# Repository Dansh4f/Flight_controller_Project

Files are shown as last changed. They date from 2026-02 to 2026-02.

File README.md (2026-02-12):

# STM32F405 Flight Controller — Custom PCB Design

A compact, manufacturing-ready flight controller PCB designed around the STM32F405RGT6 (ARM Cortex-M4). This repository contains the Altium source files for a two-layer board focused on clean power distribution, modular sensor integration, and reliable communication for embedded flight applications.

## Highlights

- Core MCU: STM32F405RGT6 (Cortex-M4 @ 168 MHz)
- Sensors: BNO055 (IMU), MS5611 (barometer), depth sensor
- Wireless/comms: UWB (SPI interface), GPS (UART), SBUS receiver input
- Interfaces: multiple SPI buses, shared I2C, UARTs, USB
- Motor PWM outputs with dedicated connector
- On-board 3.3V regulation and input protection (BAT54C + MIC5504 LDO)

## System Overview

The design integrates MCU, sensors, and power subsystems to provide a reliable flight controller platform. Main subsystems:

- MCU core and support circuits (oscillator, VCAP, decoupling, reset/boot)
- Power input protection and 3.3V regulation
- Sensor interfaces (I2C and SPI) and connectors for expandability
- SBUS receiver input conditioning and motor PWM outputs
- USB for programming and diagnostics

## Microcontroller & Board Considerations

Design decisions made for the `STM32F405RGT6`:

- Individual decoupling capacitors for each VDD/VDDA pin
- Required VCAP caps and analog filtering for stable operation
- Ferrite bead isolation for analog supply (3.3VA)
- External crystal oscillator with proper load capacitors
- Boot configuration and reset network implemented for robust programming

## Power Architecture

Input sources:

- USB 5V (programming/power)
- External 5V header (battery or regulated input)

Protection & regulation:

- BAT54C Schottky diode for input protection/OR-ing
- MIC5504 LDO to provide regulated 3.3V to MCU and sensors
- Short, wide power traces and a bottom-layer ground pour for low impedance
- Proper input/output decoupling and via stitching for returns

Power routing was prioritized in layout to minimize noise injection into analog circuits.

## Sensors & Peripherals

- BNO055 IMU — I2C, with reset/interrupt lines routed
- MS5611 barometer — SPI with dedicated CS and local decoupling
- UWB module — SPI2 bus with IRQ and reset
- Depth sensor — I2C on the shared sensor bus
- GPS — UART interface on dedicated header

Components are placed and routed to keep analog sensors away from high-current traces.

## Communications & Signal Conditioning

- Multiple SPI buses isolate high-speed peripherals for signal integrity
- Shared I2C bus enables sensor expansion
- UARTs for GPS and debug
- SBUS receiver input uses an NPN transistor-based level shifter and pull-ups for reliable logic levels

## Motor PWM

Motor outputs are brought to a dedicated connector with shield/ground considerations and short route lengths from the MCU PWM pins.

## PCB Layout Strategy

- 2-layer PCB with bottom ground plane
- Ground via stitching in key areas
- Routing priority: power → decoupling → high-speed SPI → connectors
- Controlled trace widths for power, short SPI routes, and clear mechanical anchor points

## Files in this repository

- `Flight_controller_Project.PrjPcb` — Altium project file
- `PCB1.PcbDoc` — PCB layout document
- `Sheet1.SchDoc`, `Sheet2.SchDoc`, `Sheet3.SchDoc` — schematic pages
- `*.SchLib`, `*.PcbLib` — component libraries
- `Project Outputs for Flight_controller_Project/` — generated outputs (DRC, HTML reports)
- `.gitignore` — rules to exclude generated and temp files

## How to open (Altium Designer)

1. Open Altium Designer.
2. `File → Open Project` and choose `Flight_controller_Project.PrjPcb`.
3. Open schematic and PCB documents as needed.

## PCB Preview — 3D View

The image below is a 3D rendered view of the Flight Controller PCB (top side). It highlights component placement, connector locations, and the overall board layout intended for manufacturing and mechanical integration.

<p align="center">
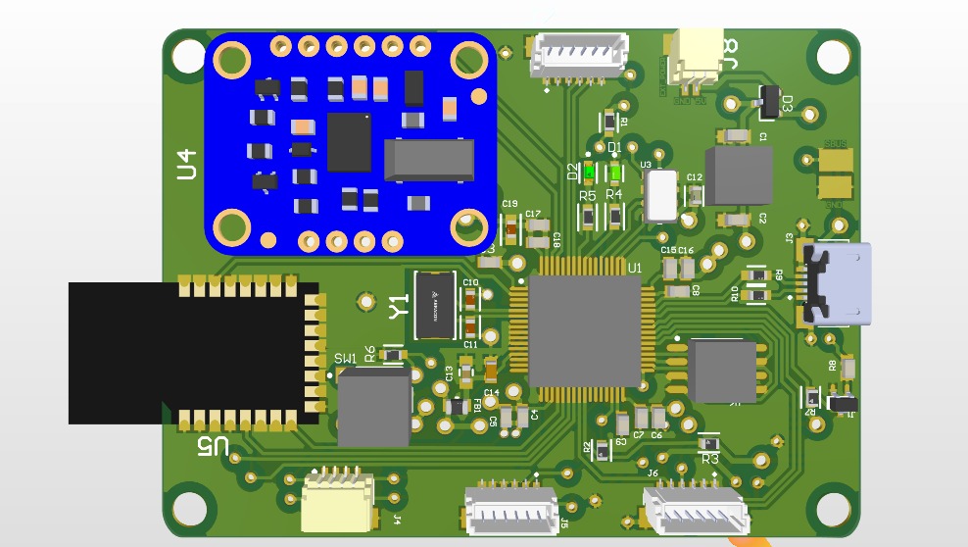
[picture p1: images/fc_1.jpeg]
3D render of Flight Controller PCB
	
</p>

## Contact

**Author:** Swastik Kumar

---

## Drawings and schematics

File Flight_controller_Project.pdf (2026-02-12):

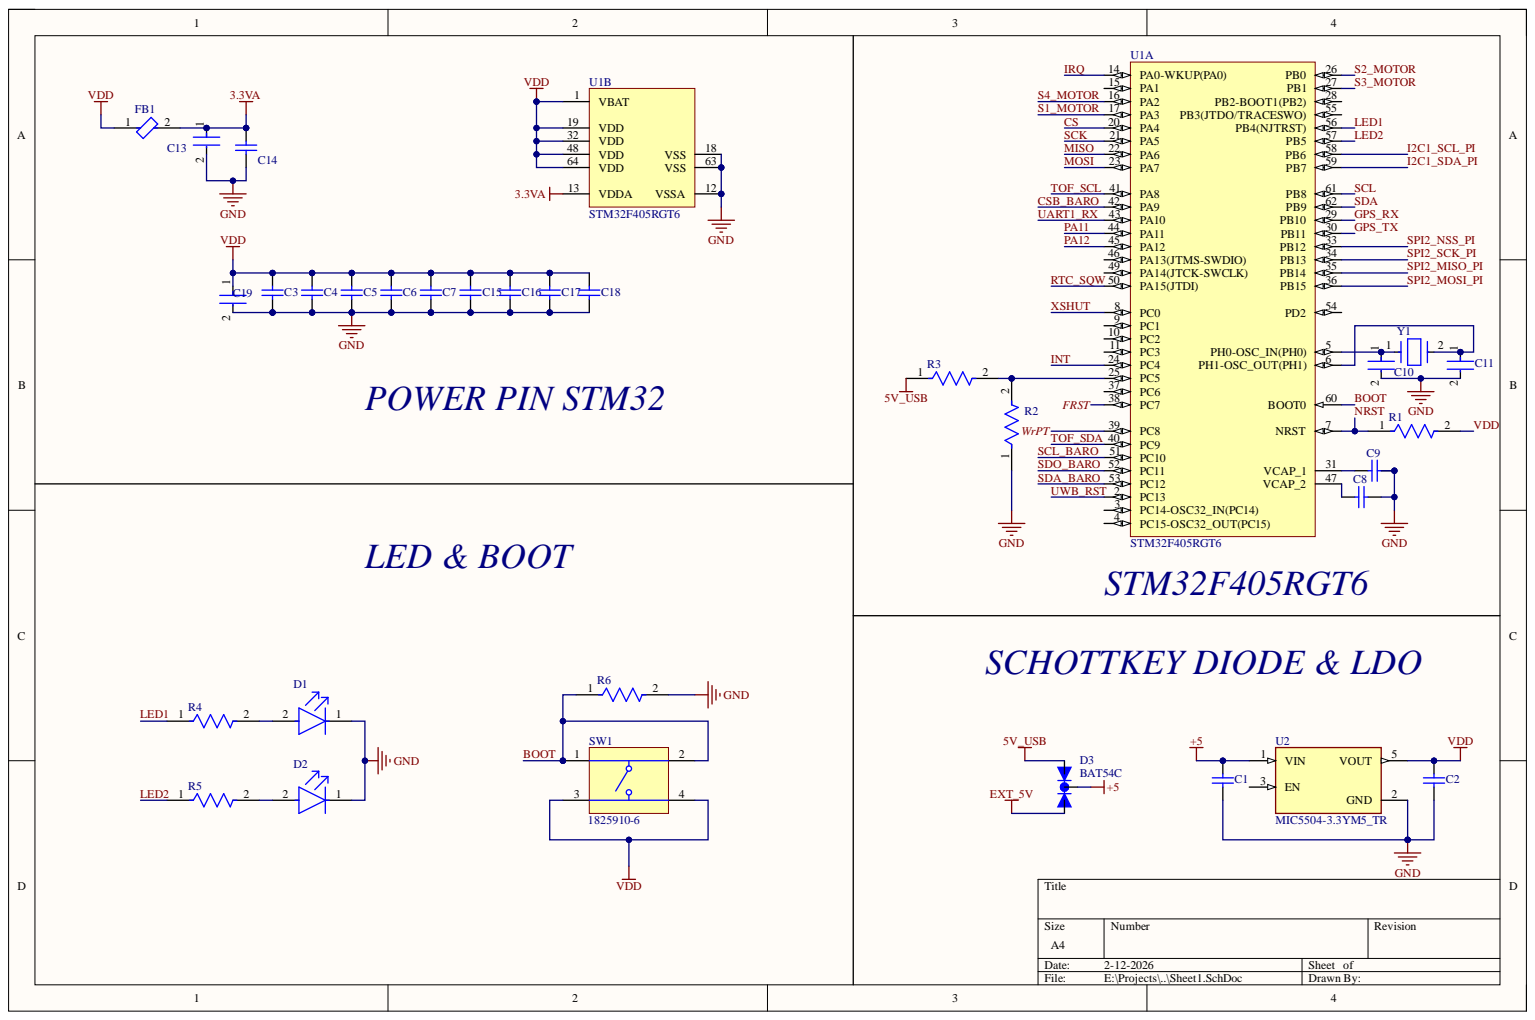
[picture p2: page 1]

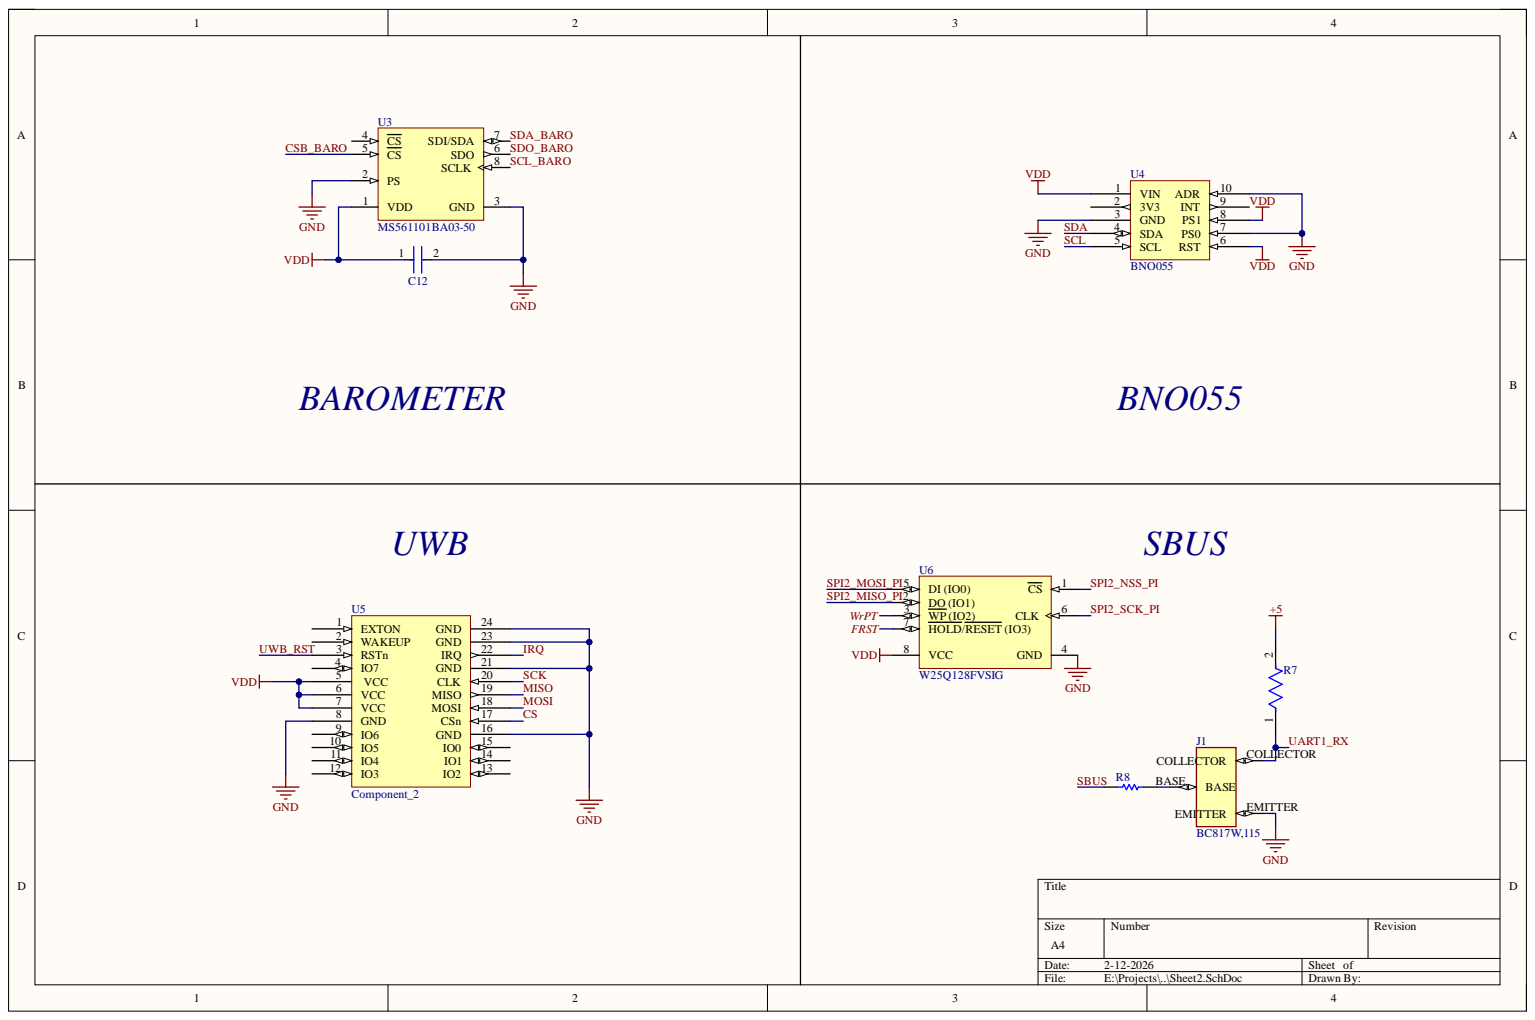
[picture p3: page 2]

VCC 7

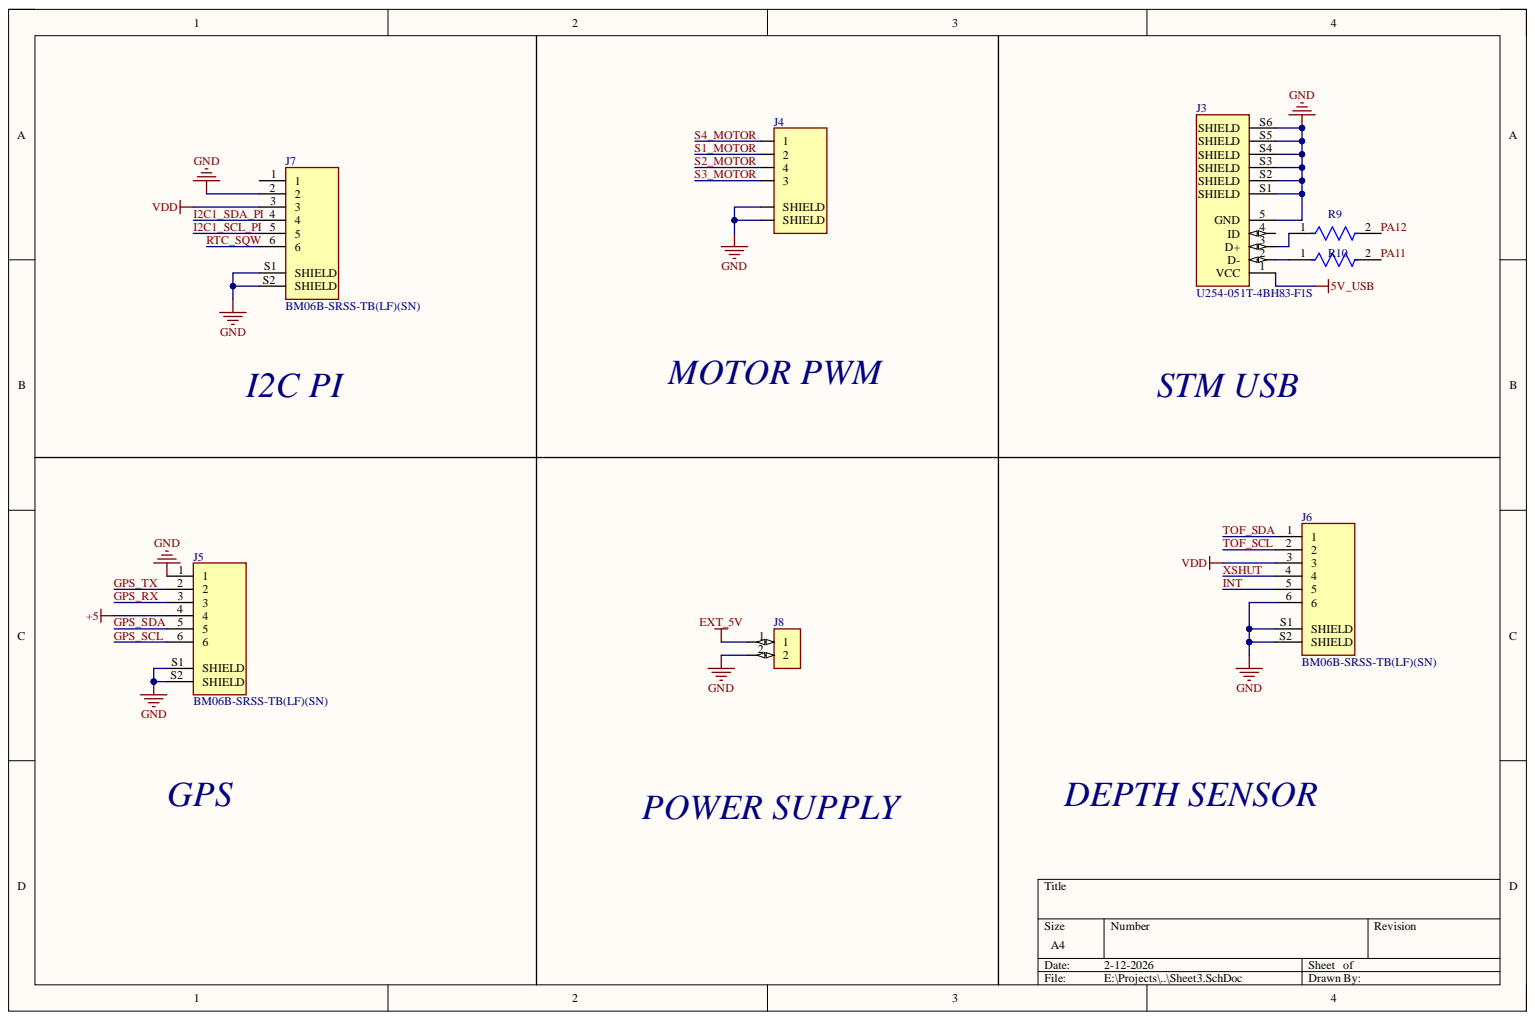
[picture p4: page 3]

6B-SRSS-TB(LF)(SN

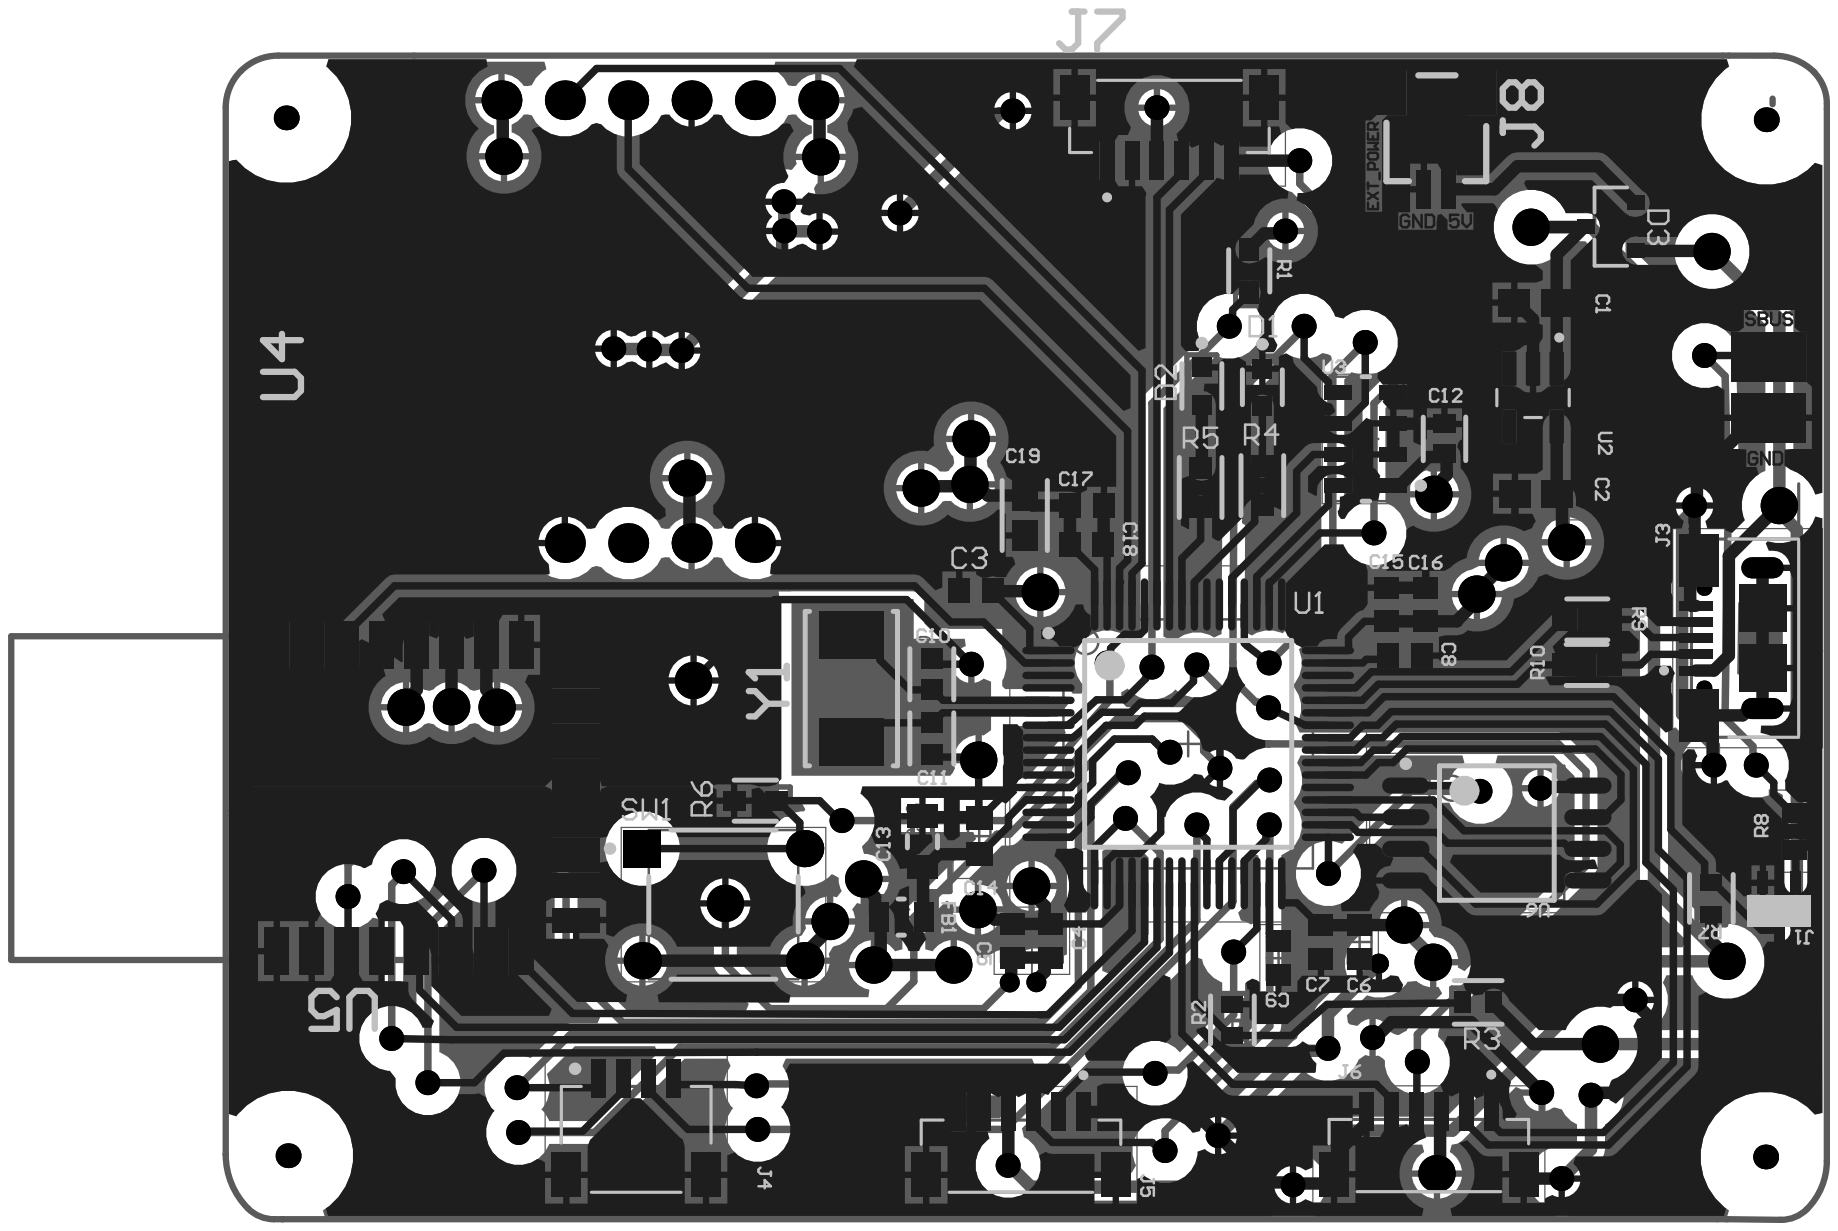
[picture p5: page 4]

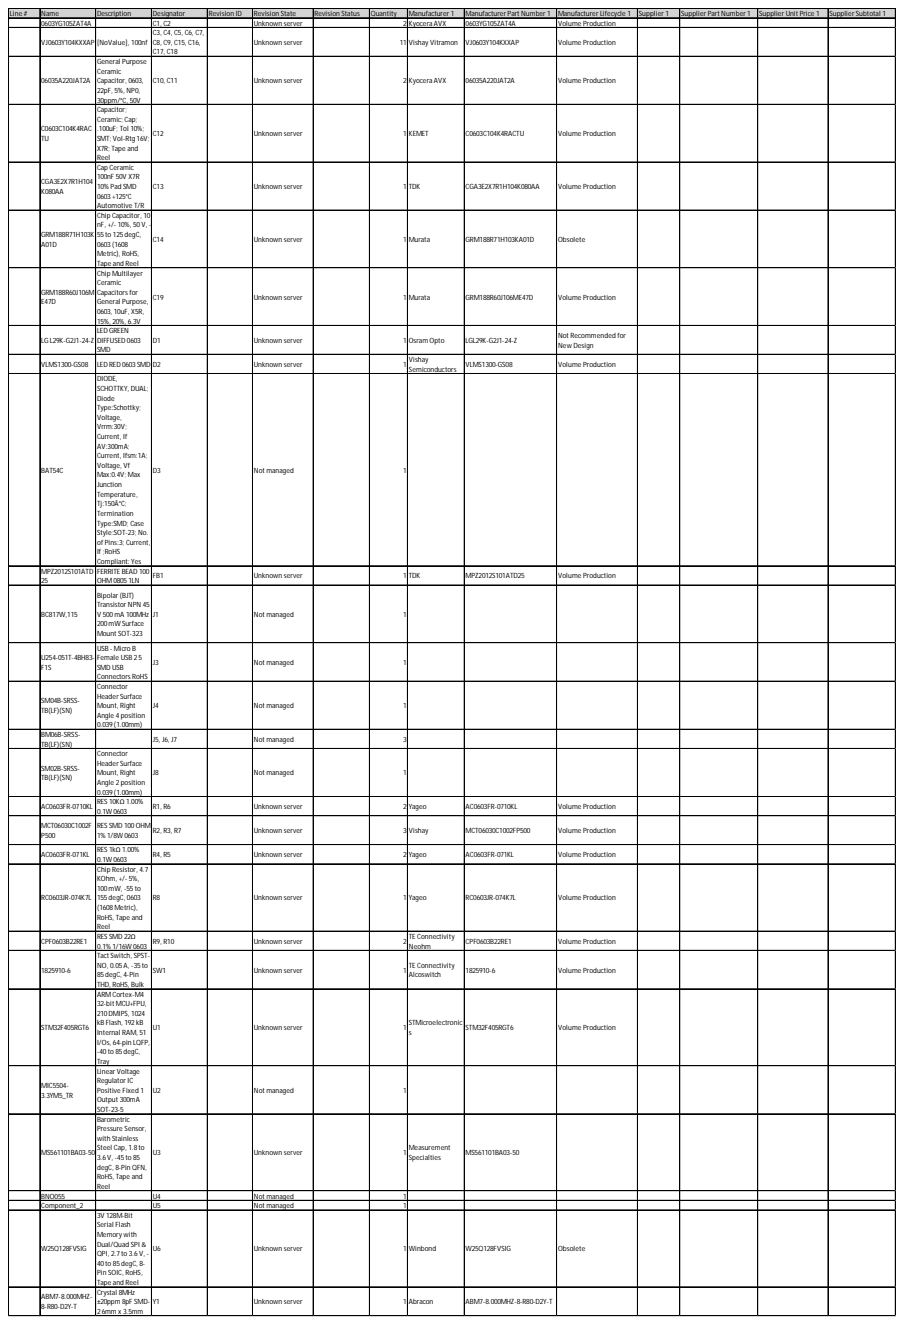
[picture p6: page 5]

Line # | Name | Description | Designator | Revision ID | Revision State | Revision Status | Quantity | Manufacturer 1 | Manufacturer Part Number 1 | Manufacturer Lifecycle 1 | Supplier 1 | Supplier Part Number 1 | Supplier Unit Price 1 | Supplier Subtotal 1

0603YG105ZAT4A | | C1, C2 | | Unknown server | | | 2 Kyocera AVX | 0603YG105ZAT4A | Volume Production
VJ0603Y104KXXAP [NoValue], 100nf | | C3, C4, C5, C6, C7, C8, C9, C15, C16, C17, C18 | | Unknown server | | 11 Vishay Vitramon | | VJ0603Y104KXXAP | Volume Production

06035A220JAT2A | General Purpose Ceramic Capacitor, 0603, 22pF, 5%, NP0, 30ppm/°C, 50V | C10, C11 | | Unknown server | | | 2 Kyocera AVX | 06035A220JAT2A | Volume Production

C0603C104K4RAC TU | Capacitor; Ceramic; Cap; .100uF; Tol 10%; SMT; Vol-Rtg 16V; X7R; Tape and Reel | C12 | | Unknown server | | | 1 KEMET | C0603C104K4RACTU | Volume Production

CGA3E2X7R1H104 K080AA | Cap Ceramic 100nF 50V X7R 10% Pad SMD 0603 +125°C Automotive T/R | C13 | | Unknown server | | | 1 TDK | CGA3E2X7R1H104K080AA | Volume Production

GRM188R71H103K A01D | Chip Capacitor, 10 nF, +/- 10%, 50 V, -55 to 125 degC, 0603 (1608 Metric), RoHS, Tape and Reel | C14 | | Unknown server | | | 1 Murata | GRM188R71H103KA01D | Obsolete

GRM188R60J106M E47D | Chip Multilayer Ceramic Capacitors for General Purpose, 0603, 10uF, X5R, 15%, 20%, 6.3V | C19 | | Unknown server | | | 1 Murata | GRM188R60J106ME47D | Volume Production

LG L29K-G2J1-24-Z | LED GREEN DIFFUSED 0603 SMD | D1 | | Unknown server | | | 1 Osram Opto | LGL29K-G2J1-24-Z | Not Recommended for New Design

VLMS1300-GS08 | LED RED 0603 SMD D2 | | | Unknown server | | | 1 Vishay Semiconductors | VLMS1300-GS08 | Volume Production

BAT54C | DIODE, SCHOTTKY, DUAL; Diode Type:Schottky; Voltage, Vrrm:30V; Current, If AV:300mA; Current, Ifsm:1A; Voltage, Vf Max:0.4V; Max Junction Temperature, Tj:150Â°C; Termination Type:SMD; Case Style:SOT-23; No. of Pins:3; Current, If ;RoHS Compliant: Yes | D3 | | Not managed | | | 1

MPZ2012S101ATD 25 | FERRITE BEAD 100 OHM 0805 1LN | FB1 | | Unknown server | | | 1 TDK | MPZ2012S101ATD25 | Volume Production

BC817W,115 | Bipolar (BJT) Transistor NPN 45 V 500mA 100MHz 200mW Surface Mount SOT-323 | J1 | | Not managed | | | 1

U254-051T-4BH83-F1S | USB - Micro B Female USB 2 5 SMD USB Connectors RoHS | J3 | | Not managed | | | 1

SM04B-SRSS-TB(LF)(SN) | Connector Header Surface Mount, Right Angle 4 position 0.039 (1.00mm) | J4 | | Not managed | | | 1

BM06B-SRSS-TB(LF)(SN) | | J5, J6, J7 | | Not managed | | | 3

SM02B-SRSS-TB(LF)(SN) | Connector Header Surface Mount, Right Angle 2 position 0.039 (1.00mm) | J8 | | Not managed | | | 1

AC0603FR-0710KL | RES 10KΩ 1.00% 0.1W 0603 | R1, R6 | | Unknown server | | | 2 Yageo | AC0603FR-0710KL | Volume Production

MCT06030C1002F P500 | RES SMD 100OHM 1% 1/8W 0603 | R2, R3, R7 | | Unknown server | | | 3 Vishay | MCT06030C1002FP500 | Volume Production

AC0603FR-071KL | RES 1kΩ 1.00% 0.1W 0603 | R4, R5 | | Unknown server | | | 2 Yageo | AC0603FR-071KL | Volume Production

RC0603JR-074K7L | Chip Resistor, 4.7 KOhm, +/- 5%, 100mW, -55 to 155 degC, 0603 (1608 Metric), RoHS, Tape and Reel | R8 | | Unknown server | | | 1 Yageo | RC0603JR-074K7L | Volume Production

CPF0603B22RE1 | RES SMD 22Ω 0.1% 1/16W 0603 | R9, R10 | | Unknown server | | | 2 TE Connectivity Neohm | CPF0603B22RE1 | Volume Production

1825910-6 | Tact Switch, SPST-NO, 0.05 A, -35 to 85 degC, 4-Pin THD, RoHS, Bulk | SW1 | | Unknown server | | | 1 TE Connectivity Alcoswitch | 1825910-6 | Volume Production

STM32F405RGT6 | ARM Cortex-M4 32-bit MCU+FPU, 210 DMIPS, 1024 kB Flash, 192 kB Internal RAM, 51 I/Os, 64-pin LQFP, -40 to 85 degC, Tray | U1 | | Unknown server | | | 1 STMicroelectronic s | STM32F405RGT6 | Volume Production

MIC5504-3.3YM5_TR | Linear Voltage Regulator IC Positive Fixed 1 Output 300mA SOT-23-5 | U2 | | Not managed | | | 1

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

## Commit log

2026-02-12 Initial commit: add Altium PCB project
    [BNO055.PcbLib, BNO055.SchLib, BU01 UWB.PcbLib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]
2026-02-12 Add PCB preview PDF and update README with preview link
2026-02-12 Embed PCB image link in README (images/pcb_render.png)
2026-02-12 Add PCB render image (images/fc_1.jpeg)
2026-02-12 Show uploaded PCB image in README (images/fc_1.jpeg)
